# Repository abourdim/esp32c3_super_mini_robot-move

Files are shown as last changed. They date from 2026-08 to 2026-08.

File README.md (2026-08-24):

# 🤖 esp32c3_super_mini_robot-move — b3 on the `30_esp32_c3_move` board

A port of [`esp32c3_super_mini_robot-bit-rxy`](https://github.com/abourdim/esp32c3_super_mini_robot-bit-rxy)
("b3") onto the **`30_esp32_c3_move`** carrier board, plus a panning sonar head
the original does not have. Driven over Bluetooth Low Energy from the
[rxy web app](https://github.com/abourdim/rxy_web) — no install, no account, no
WiFi.

**The robot owns the layout.** The app is a generic renderer: it connects, asks
the robot for its panel, and draws whatever comes back. There is no per-robot
build of the app.

## Faithful to b3

Every module b3 has is still in the tree — buzzer, NeoPixels, battery sense,
board LEDs, OLED, both NeoPixel demos, all eight panels. Nothing was deleted.
What changed is the pin map, because the two carrier boards share an MCU and
nothing else.

What is **not fitted** on this build is switched off at a single `#define`
each, so it compiles out rather than failing at runtime:

| feature | b3 | here | state |
|---|---|---|---|
| left / right drive servo | GPIO 6 / 3 | **5 / 10** — J5 / J12, level-shifted | ✅ |
| HC-SR04 | 21 / 20 | **6 / 7** — J10, level-shifted | ✅ |
| head servo | *(none)* | **1** — J6 | ✅ |
| button / OTA | 0 (module BOOT) | **3** — SW1 | ✅ |
| green / red LED | 1 / 10 | **0 / 21** — J7 / J8 | ✅ |
| NeoPixel strip | 5 (or 10) | 20 — J9 | `CONFIG_NEOPIXELS_ENABLED 0` |
| buzzer | 4 | 4 — SW2 pads | `CONFIG_BUZZER_ENABLED 0` |
| battery sense | 4 | 4 — SW2 pads, **no divider on the board** | reads meaningless |
| OLED | I²C 8 / 9 | 8 / 9 — module pads, **not wired** | `CONFIG_OLED_ENABLED 0` |

Turning the strip off is worth more than it looks: its default French-flag
effect calls `delay(1000/60)` on **every** `loop()` iteration, so an absent
strip still paced the whole robot at 60 Hz to animate nothing.

The OLED keeps its runtime presence-probe for the day the wires go on, but with
the feature off nothing touches the I²C bus at all — not even the five-second
re-probe, which would otherwise poke a dead bus forever. Set
`CONFIG_OLED_ENABLED 1` once SDA/SCL/3V3/GND are on the module's pads; nothing
else needs changing. Wiring and the strapping-pin reasoning:
[`02_hardware/README.md`](02_hardware/README.md#attaching-the-oled).

Board source and the full netlist-derived pin map: [`02_hardware/`](02_hardware/).

## Three servos need four PWM timers

b3 allocates **one** LEDC timer and attaches two servos, which exactly fits.
The head makes three, and ESP32Servo does not warn when it runs short — it
prints `All PWM timers allocated! Can't accomodate 50.000 Hz` and **halts
inside `attach()`**, so `setup()` never returns.

That failure is invisible from outside. NimBLE has already started on its own
task by then, so the robot still advertises and the app still connects; it just
never answers anything, because `remotexy_handler()` lives in `loop()` and
`loop()` has never run. It presents as a protocol bug and is not one.

`setup()` now allocates all four.

## The 3-pin headers double as FET gates

J6, J7, J8 and J9 carry the same nets as Q1–Q4's gates, which drive the J1–J4
screw terminals and their yellow indicator LEDs. Anything plugged into a 3-pin
header switches its paired screw terminal in sympathy, so **leave J1–J4
unpopulated**. The upside is free activity indicators: D6–D9 light along with
whatever is on the header, so the link LEDs are visible even with nothing
plugged in.

## Why the button moved off GPIO 0

b3 uses the SuperMini's own BOOT button for the three-second OTA hold, and that
button exists here too. But on this board GPIO 0 is Q2's gate, so the gesture
would switch the J2 output on for the length of the hold — and GPIO 0 is more
useful as the green LED. SW1 is a real button with its own pull-up that drives
nothing else.

## Drive direction

`CONFIG_SERVO_INVERT_DRIVE` flips both channels. Both wheels ran backwards on
this chassis — that is motor polarity, not a left/right mix-up, and swapping
the two pins would have given a robot that spins instead. The flip is applied
to the command before the mix becomes pulses, so trim and the speed cap stay in
the frame they were written for, and it corrects the steering with it: with the
polarity wrong, a spin-left command was coming out as spin-right.

## The head, the radar, and sweep

The head servo is the one thing here that b3 does not have. It gives the app's
**radar** widget a bearing to plot against — the radar carries no value of its
own, it reads the distance gauge and the head slider by id.

**Sweep** is a toggle in the DISTANCE group. The head steps one notch per
telemetry pass rather than on a timer of its own, and the step happens *after*
the pass has sent this cycle's distance and angle. That ordering is the point:
the radar plots (angle, distance) pairs, and stepping independently would paint
readings at bearings the sensor was not pointing at when they were taken. Each
step then gets a full 500 ms to settle before the next measurement. 15° steps
across 10–170° is about 5.5 s per sweep.

Reversal happens **at** each limit, not past it. `moveHead()` clamps anyway,
but bouncing off the clamp parks the head on its end stop for an extra pass
every sweep — a stutter on the scope, and a stalled servo while it lasts.

Dragging the slider takes the head off sweep, otherwise the servo fights you
and the slider snaps back on the next pass. Leaving sweep re-centres.

The bearing is published every telemetry pass. Without that the radar plots at
whatever `head` last reported, which was its default — the head would sweep and
the scope would show a beam frozen at 90°.

**Head trim** (`head_off`, plus H−1 / H+1 buttons) is mechanical centring: a
pan mount is glued or screwed on by hand, so commanding 90° almost never points
dead ahead. The offset is applied where the servo is *written*, not to the
bearing that gets reported — the radar has to plot where the sensor is really
aimed, which is the corrected direction. Like the wheel trims it lives in NVS,
because it describes how the robot was assembled rather than how it is being
driven; and like them it rides the save-settle, so dragging the slider across
its range costs one flash write rather than sixty.

`CONFIG_SERVO_HEAD_MIN` / `_MAX` are the **mechanical** limits of your pan
mount, not 0–180. Narrow them to what the mount clears — a servo told to go
past its stop sits there stalled, drawing full stall current off the same rail
as the C3.

## Panels

b3's eight, plus a ninth — **Radar** — switched with the **Level** selector;
the choice is kept in NVS. The Radar panel is one subsystem on its own: the
scope, the head slider, Sweep, the head trim, and the distance readout the
radar is plotting, so the panel explains itself — you can see the number each
blip came from.

The new level is appended to the enum rather than inserted, because the level
index lives in NVS: renumbering the existing entries would silently move an
upgraded robot to a different panel. And since every layout carries its own
copy of the selector's options, all nine blobs were rewritten — otherwise the
new level would be unreachable from wherever you happened to be.

Expert has been cut down to what this board actually has:

- **removed** — the DISPLAY group (no OLED) and the SOUND group (no buzzer)
- **removed** — the six strip widgets from LIGHTS; the two board LEDs stay,
  they are real, and their J7/J8 headers light the onboard yellows too
- **moved** — TRIM is no longer its own group; all eight widgets sit inside
  DRIVE, which is where you use them, tuning while driving and watching the pull
- **added** — the head slider, the sweep toggle, and the radar, in DISTANCE

> ⚠️ **`gen_test_layouts.py` writes `test_decls.h`, which nothing includes.**
> The live blobs are hardcoded in `03_bit-rxy.cpp`, so running the generator
> changes nothing that reaches the board. It needs a splice step — S2's
> `gen_layouts.py` has the logic to copy — or it should be deleted. Until then,
> layout edits go into the blobs directly.

## Build and flash

```bash
cd 01_software/01_app && pio run -e esp32-c3-devkitm-1 -t upload
```

After the first USB flash, hold **SW1 for 3 seconds** to enter WiFi OTA mode.
Hold to 8 seconds to forget the saved network. The device is reachable as
`wdiy-move`, and the setup AP is `WDIY-Robot-Setup`.

BLE device name is `diy_app_mv`, distinct from b3's `diy_app_b3` so the two are
told apart in the scanner when both are powered on in the same room.

**The image is at 91.5% of flash** — roughly 110 KB spare on the default
partition table. Enough for tuning, not for another subsystem.

Note that with native USB-CDC the serial monitor attaches *after* boot, so you
will usually see nothing at startup. That is normal, not a fault.

## Before you build one

Three board facts firmware cannot paper over — the long form is in
[`02_hardware/README.md`](02_hardware/README.md):

- **J1–J4 must stay unpopulated** while anything is on J6–J9. Same nets.
- **J6 has no level shifter.** J5, J12 and J10 run through the TXB0104 and get
  clean 5 V logic; J6 carries the raw 3.3 V pin. Most hobby servos accept that.
- **The servo rail needs 470–1000 µF** at the connectors, fed from the input
  terminal rather than through the SuperMini's 5 V pin. Three drive servos on a
  rail with 100 nF browns the C3 out mid-drive, which reads as a random reboot.

## Known issues

- **Trim is applied with the wrong sign**, inherited from b3. It is added to
  both wheels, but the right channel's pulse range is inverted, so a positive
  trim pushes the two wheels in *opposite* physical directions. With b3's
  defaults of `5`/`5` an idle robot slowly rotates on the spot. Either zero the
  two `CONFIG_SERVO_SPEED_STOP_*_OFFSET` values or port S2's fix (`10c1468`),
  which subtracts on the inverted side.
- **`01_software/01_app/02_web/`** is b3's site and still describes b3's pin
  map. Its Pages workflow is set to manual trigger only, so a push cannot
  publish a site that is wrong about this robot. Rewrite it before re-enabling.

## Wiki

A full illustrated walkthrough — clone, build, flash, verify, plus the board's
pin map and how the sweep is paced — is on the wiki in three languages:

- [Robot MV (English)](https://abourdim.github.io/wiki/robot-mv-en.html)
- [Robot MV (Français)](https://abourdim.github.io/wiki/robot-mv.html)
- [Robot MV (العربية)](https://abourdim.github.io/wiki/robot-mv-ar.html)

Powered by [Workshop-DIY.org](https://workshop-diy.org)

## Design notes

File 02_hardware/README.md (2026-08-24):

# 🔌 Hardware

KiCad source, PCB renders and fab output for **`30_esp32_c3_move`**, the board
this firmware targets. Upstream lives at `01_kicad/30_esp32_c3_move/`.

## Versions

| Version | Status | Folder |
|---|---|---|
| **v1** | ✅ **Current — fabricated, and what the firmware is written against** | [`v1/`](v1/) |
| v2 | 📝 Planning stub, not a revision | [`v2/`](v2/) |

**v2 is not a new board.** Its PCB is byte-identical to v1 and it carries the
same 98 components; the only differences are one schematic block nudged 14 mm,
a project rename, and a to-do note dated 02/06/2025:

> add 2 neo pixel · oled connector · buzzer · battery level · large soldering
> footprint for the transistor

None of those are implemented. It is kept here because it is where that plan is
written down, not because it builds anything different.

## The pin map, and where it came from

Read out of `v1/30_esp32_c3_move.kicad_pcb` by walking footprint pads to nets —
**not** from the schematic, which labels every net `gpio_NN` and records nothing
about what it drives. `00_config.h` is the firmware-side copy of this table.

| GPIO | Connector | Used for |
|---|---|---|
| 5 | J5, 3-pin, via TXB0104 | left drive servo |
| 10 | J12, 3-pin, via TXB0104 | right drive servo |
| 6 / 7 | J10, 4-pin, via TXB0104 | HC-SR04 trig / echo |
| 1 | J6, 3-pin, **raw 3.3 V** · also Q1 gate → J1 | head servo |
| 0 | J7, 3-pin · also Q2 gate → J2 | green LED |
| 21 | J8, 3-pin · also Q3 gate → J3 | red LED |
| 20 | J9, 3-pin · also Q4 gate → J4 | NeoPixel strip |
| 3 | SW1, 10k pull-up R10 | button, OTA hold |
| 4 | SW2, 10k pull-up R11 | 🔧 buzzer + battery sense, bodged to the pads |
| **2, 8, 9** | **nowhere — module pads only** | 🔧 OLED on 8/9, four wires |

The four 3-pin headers are the same nets as the FET gates, so anything on
J6–J9 switches its paired screw terminal too. **Leave J1–J4 unpopulated.** The
compensation is that D6–D9 become free activity indicators for whatever is on
the header.

Each switched output has a 1N4007 flyback (D1–D4), a 10k gate pull-down
(R6–R9) and a yellow state LED (D6–D9 + R1–R4). The SK12D07VG4 slide switch
gates the input rail; J11 (screw) and J13 (JST-PH) both feed it.

## Three things to know before building one

**The 3-pin headers share nets with the screw terminals.** GPIO 1 is Q1's gate
*and* J6's signal pin; the same pairing holds for J7/J2, J8/J3 and J9/J4. A
servo on J6 pulses the J1 output at 50 Hz and flickers D6 continuously; a load
on J1 makes the head twitch. Populate the header or the terminal, never both.
Firmware cannot arbitrate this — it is a copper fact.

**J6 has no level shifter.** J5, J12 and J10 all run through the TXB0104 and
get clean 5 V logic. J6 carries the raw 3.3 V pin. Most hobby servos accept
that; a fussy one is the case where this board bites.

**The servo rail needs bulk capacitance.** Three servos share `VCC` with the
ESP32 and v1 has only 100 nF on that rail. An SG90 pulls ~700 mA stalled with
a larger startup surge, and these are drive servos — they run constantly. Add
**470–1000 µF at the servo connectors**, and feed servo power straight from the
input terminal rather than through the SuperMini's 5 V pin, so servo current
does not run through the module. Without this the rail dips and the C3 browns
out mid-drive, which reads as a random reboot.

## Attaching the OLED

GPIO 2, 8 and 9 reach the SuperMini's pads and no connector, so the SSD1306 is
four wires soldered to the module itself. This is what v2's "oled connector"
note is meant to fix.

| OLED pin | goes to |
|---|---|
| SDA | module **GPIO 8** |
| SCL | module **GPIO 9** |
| VCC | module **3V3** — *not* 5V, see below |
| GND | any GND |

**Take VCC from 3V3, not 5V.** Most SSD1306 modules accept either, but the
module's own I2C pull-up resistors go to whatever you feed it. On 5V those
pull-ups would hold SDA and SCL at 5V, and the C3's GPIOs are not 5V tolerant.

**The pull-ups are also what make the board boot.** GPIO 8 and 9 are both
strapping pins on the ESP32-C3, and both need to be high at reset — GPIO 9 low
at reset is what selects download mode. The module's pull-ups hold them there,
which is exactly why this pin pair works on b3 too. Flashing still works
normally: the module's BOOT button pulls GPIO 9 low against the pull-up.

The firmware probes `0x3C` at boot and re-probes every five seconds while no
screen is answering, so a wire that makes contact late or works loose recovers
without a power cycle. Watch serial for `[OLED] found` or `[OLED] appeared on
the bus`. If you get neither, the usual cause is a module strapped to **0x3D**
instead of 0x3C — some boards have a solder jumper for it.

Powered by [Workshop-DIY.org](https://workshop-diy.org)

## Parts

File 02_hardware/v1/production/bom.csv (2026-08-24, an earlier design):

Designator | Footprint | Quantity | Value | LCSC Part #
C1, C2 | 0805 | 2 | 100nF
D1, D2, D3, D4 | D_SOD-123F | 4 | 1N4007
D6, D7, D8, D9 | 0805 | 4 | yellow
J1, J11, J2, J3, J4 | TerminalBlock_Phoenix_MPT-0,5-2-2.54_1x02_P2.54mm_Horizontal | 5 | Screw_Terminal_01x02
J10 | PinHeader_1x04_P2.54mm_Vertical | 1 | Conn_01x04_Pin
J12, J5, J6, J7, J8, J9 | PinHeader_1x03_P2.54mm_Vertical | 6 | Conn_01x03_Pin
J13 | JST_PH_S2B-PH-K_1x02_P2.00mm_Horizontal | 1 | Conn_01x02_Pin
Q1, Q2, Q3, Q4 | SOT-23_Handsoldering | 4 | 2N7002
R1, R2, R3, R4 | 0805 | 4 | 1k
R10, R11, R5, R6, R7, R8, R9 | 0805 | 7 | 10k
SW1, SW2 | SW_Push_1P1T_NO_6x6mm_H9.5mm | 2 | SW_Omron_B3FS
U1 | MODULE_ESP32-C3_SUPERMINI | 1 | ESP32-C3_SUPERMINI
U2 | SK12D07VG4 | 1 | SK12D07VG4
U3 | TSSOP-14_4.4x5mm_P0.65mm | 1 | TXB0104PW

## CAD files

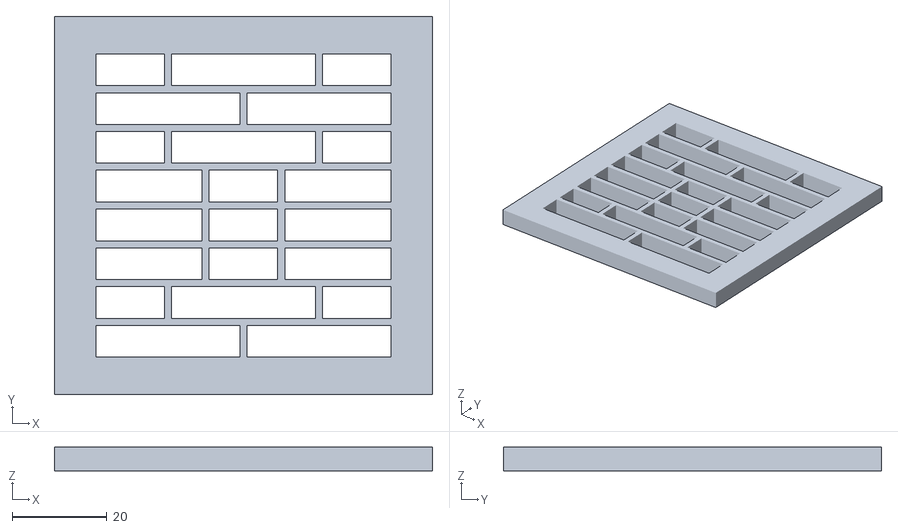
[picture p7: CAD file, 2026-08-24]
01_software/4_wled/WLED/usermods/word-clock-matrix/Word Clock Baffle.stl
80.0 x 80.0 x 5.00

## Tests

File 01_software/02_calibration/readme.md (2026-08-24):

# Wheel calibration sketch

Finds each wheel's true stop point on continuous-rotation servos. Same BLE/OLED/OTA plumbing as `01_app`, but the widgets drive raw servo pulses directly (0-180) instead of the arcade-mixed joystick/D-Pad — no guessing which combined stick position corresponds to a given pulse.

## Flash it

```bash
cd 01_software/02_calibration
./launch.sh flash
```

## Use it

Open [bit-rxy](https://abourdim.github.io/bit-rxy/), connect to `diy_calib_b3`. Layout:

- **Left / Right sliders** — drag for coarse adjustment (0-180).
- **Left # / Right # edit fields** — type an exact number for fine adjustment; slider and edit field for the same wheel share state, whichever you touched last wins.
- **Center button** — resets both wheels to 90 (stop).

The OLED shows the live pulse value for each wheel as you adjust. Watch the actual wheel: find the pulse value where it visibly stops turning, note it down, and put it in `01_app/01_src/00_config.h` as `CONFIG_SERVO_SPEED_STOP_LEFT`/`_RIGHT` (plus whatever small `_OFFSET` correction gets it dead-centered).

## OTA

Same as `01_app` — hold the debug button ~3s to reconnect to the last WiFi network, ~8s to forget it and open the `WDIY-Calib-Setup` portal. See the [wiki article's OTA section](https://abourdim.github.io/wiki/wdiy-robot-en.html#ota) for the full walkthrough (applies identically here, just a different AP/hostname).

```bash
./ota_flash.sh <robot-ip>
```

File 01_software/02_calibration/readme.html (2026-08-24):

# 🔧 Wheel Calibration

Finds each wheel's true stop point on continuous-rotation servos — same BLE/OLED/OTA plumbing as the main app, but widgets drive raw servo pulses (0–180) directly.

## 🚀 Flash it

cd 01_software/02_calibration
./launch.sh flash

## 🎛️ Use it

Open bit-rxy (https://abourdim.github.io/bit-rxy/), connect to diy_calib_b3. Layout:

- Left / Right sliders — drag for coarse adjustment (0–180)
- Left # / Right # edit fields — type an exact number for fine adjustment; slider and edit field for the same wheel share state, whichever you touched last wins
- Center button — resets both wheels to 90 (stop)

The OLED shows the live pulse value for each wheel as you adjust. Watch the actual wheel: find the pulse value where it visibly stops turning, note it down, and put it in 01_app/01_src/00_config.h as CONFIG_SERVO_SPEED_STOP_LEFT/_RIGHT (plus whatever small _OFFSET correction gets it dead-centered).

## 📡 OTA

Same as the main app — hold the debug button ~3s to reconnect to the last WiFi network, ~8s to forget it and open the WDIY-Calib-Setup portal. See the wiki article's OTA section (https://abourdim.github.io/wiki/wdiy-robot-en.html#ota) for the full walkthrough (applies identically here, just a different AP/hostname).

./ota_flash.sh <robot-ip>

Workshop-DIY — part of the esp32c3_super_mini_robot-bit-rxy (https://github.com/abourdim/esp32c3_super_mini_robot-bit-rxy) project.

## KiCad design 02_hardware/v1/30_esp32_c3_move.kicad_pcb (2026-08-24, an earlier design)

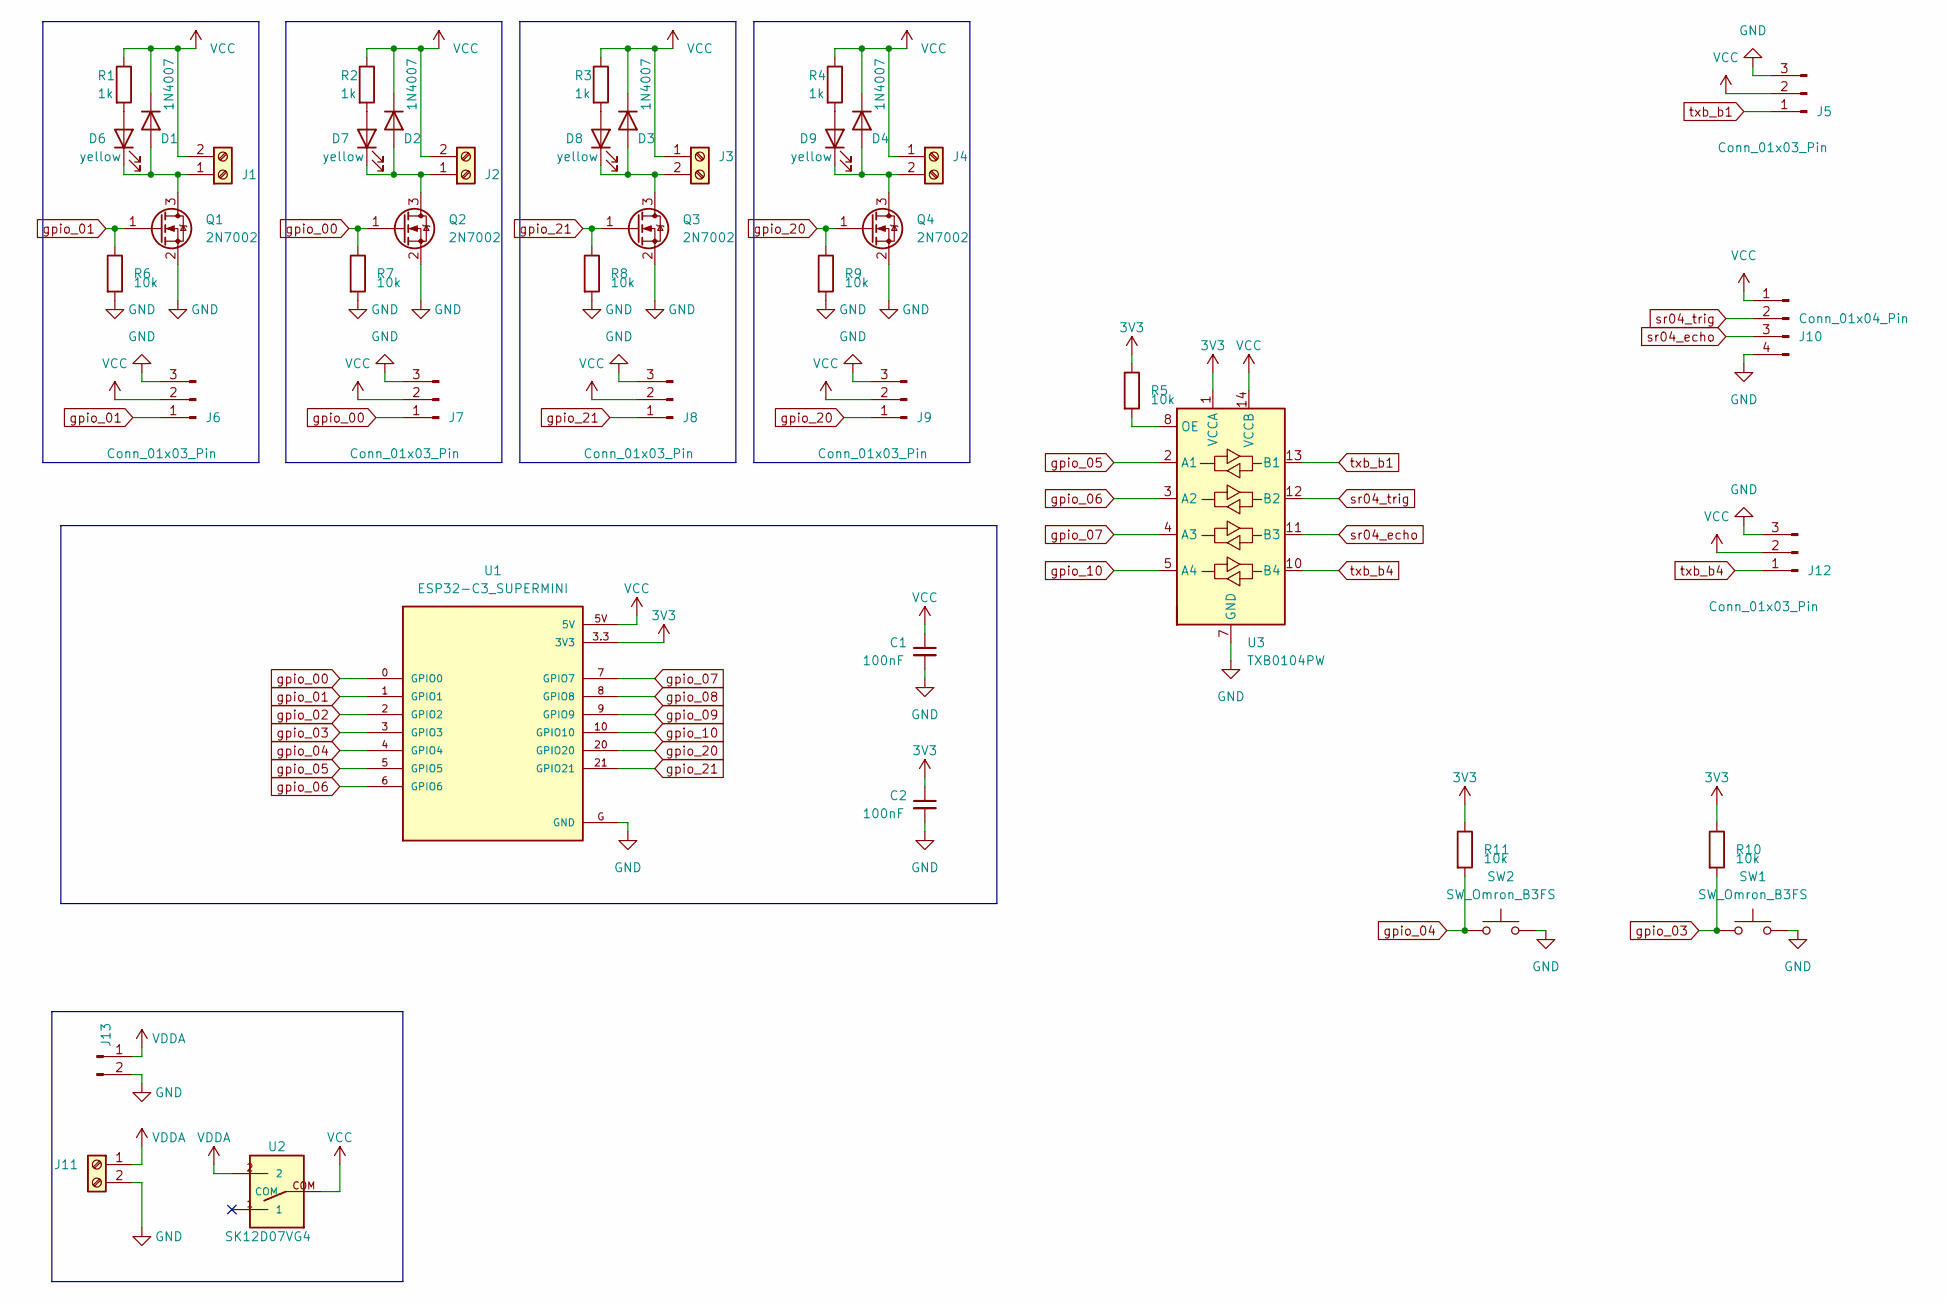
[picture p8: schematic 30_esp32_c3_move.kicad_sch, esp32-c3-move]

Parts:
C1, C2: 100nF; C_0805_2012Metric
D1, D2, D3, D4: 1N4007; D_SOD-123F
D6, D7, D8, D9: yellow; LED_0805_2012Metric_Pad1.15x1.40mm_HandSolder
J1, J2, J3, J4, J11: Screw_Terminal_01x02; TerminalBlock_Phoenix_MPT-0,5-2-2.54_1x02_P2.54mm_Horizontal
J5, J6, J7, J8, J9, J12: Conn_01x03_Pin; PinHeader_1x03_P2.54mm_Vertical
J10: Conn_01x04_Pin; PinHeader_1x04_P2.54mm_Vertical
J13: Conn_01x02_Pin; JST_PH_S2B-PH-K_1x02_P2.00mm_Horizontal
Q1, Q2, Q3, Q4: 2N7002; SOT-23_Handsoldering
R1, R2, R3, R4: 1k; R_0805_2012Metric
R5, R6, R7, R8, R9, R10, R11: 10k; R_0805_2012Metric
SW1, SW2: SW_Omron_B3FS; SW_Push_1P1T_NO_6x6mm_H9.5mm; lcsc C2837532
U1: ESP32-C3_SUPERMINI; MODULE_ESP32-C3_SUPERMINI
U2: SK12D07VG4
U3: TXB0104PW; TSSOP-14_4.4x5mm_P0.65mm

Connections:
3V3: C2.1, R5.1, R10.1, R11.1, U1.3.3 (3V3), U3.1 (VCCA)
GND: C1.2, C2.2, J5.3, J6.3, J7.3, J8.3, J9.3, J10.4, J11.2, J12.3, J13.2, Q1.2 (S), Q2.2 (S), Q3.2 (S), Q4.2 (S), R6.2, R7.2, R8.2, R9.2, SW1.2, SW2.2, U1.G (GND), U3.7 (GND)
unnamed: D1.2 (A), D6.1 (K), J1.1, Q1.3 (D)
unnamed: D2.2 (A), D7.1 (K), J2.1, Q2.3 (D)
unnamed: D3.2 (A), D8.1 (K), J3.2, Q3.3 (D)
unnamed: D4.2 (A), D9.1 (K), J4.2, Q4.3 (D)
unnamed: D6.2 (A), R1.2
unnamed: D7.2 (A), R2.2
unnamed: D8.2 (A), R3.2
unnamed: D9.2 (A), R4.2
unnamed: R5.2, U3.8 (OE)
VCC: C1.1, D1.1 (K), D2.1 (K), D3.1 (K), D4.1 (K), J1.2, J2.2, J3.1, J4.1, J5.2, J6.2, J7.2, J8.2, J9.2, J10.1, J12.2, R1.1, R2.1, R3.1, R4.1, U1.5V, U2.COM, U3.14 (VCCB)
VDDA: J11.1, J13.1, U2.2
gpio_00: J7.1, Q2.1 (G), R7.1, U1.0 (GPIO0)
gpio_01: J6.1, Q1.1 (G), R6.1, U1.1 (GPIO1)
gpio_02: U1.2 (GPIO2)
gpio_03: R10.2, SW1.1, U1.3 (GPIO3)
gpio_04: R11.2, SW2.1, U1.4 (GPIO4)
gpio_05: U1.5 (GPIO5), U3.2 (A1)
gpio_06: U1.6 (GPIO6), U3.3 (A2)
gpio_07: U1.7 (GPIO7), U3.4 (A3)
gpio_08: U1.8 (GPIO8)
gpio_09: U1.9 (GPIO9)
gpio_10: U1.10 (GPIO10), U3.5 (A4)
gpio_20: J9.1, Q4.1 (G), R9.1, U1.20 (GPIO20)
gpio_21: J8.1, Q3.1 (G), R8.1, U1.21 (GPIO21)
sr04_echo: J10.3, U3.11 (B3)
sr04_trig: J10.2, U3.12 (B2)
txb_b1: J5.1, U3.13 (B1)
txb_b4: J12.1, U3.10 (B4)

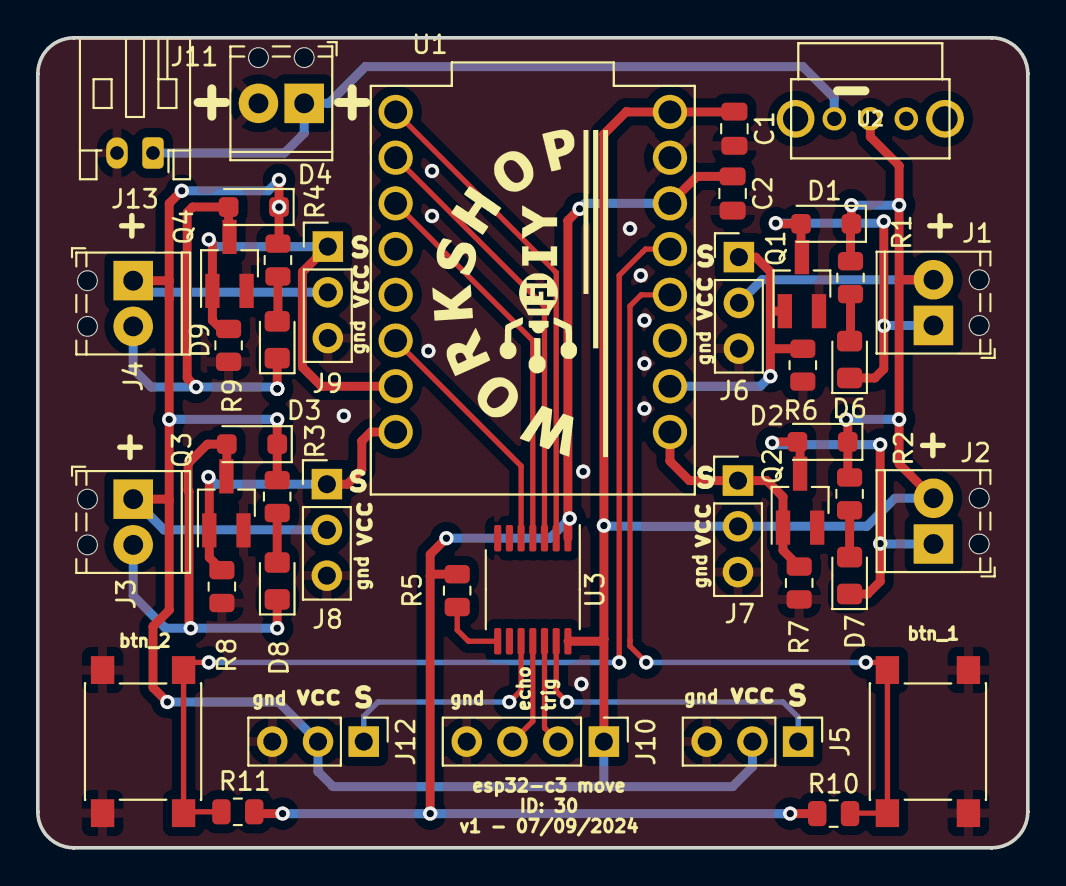
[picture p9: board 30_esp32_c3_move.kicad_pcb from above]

Board: 2 copper layers, 55.0 x 45.0 mm, 43 parts (0 on the bottom side), 27 nets.

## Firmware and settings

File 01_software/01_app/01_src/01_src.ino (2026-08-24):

///////////////////////////////////////////////
//        RemoteXY include library          //
//////////////////////////////////////////////

#include "01_includes.h"

Adafruit_SSD1306 display(SCREEN_WIDTH, SCREEN_HEIGHT, &Wire, OLED_RESET);

// ===========================================================================
void setup() {
// ===========================================================================

  // Serial for debugging
  #ifdef DEF_DERIAL_DEBUG
  Serial.begin(115200);
  #endif

  // Initialize RemoteXY
  //RemoteXY_Init();

  remotexy_init();
  
  // Allocate timers for ESP32 PWM. b3 allocates ONE and attaches two servos,
  // which exactly fits. This board has a third (the head on J6), and one more
  // servo than timers is not a warning -- ESP32Servo prints "All PWM timers
  // allocated! Can't accomodate 50.000 Hz" and then HALTS inside attach(), so
  // setup() never returns and loop() never runs.
  //
  // That failure is deceptively quiet from the outside: NimBLE has already
  // started on its own task by this point, so the robot still advertises and
  // the app still connects -- it just never gets an answer to anything,
  // because remotexy_handler() lives in loop(). It looks like a protocol bug
  // and is not one.
  ESP32PWM::allocateTimer(0);
  ESP32PWM::allocateTimer(1);
  ESP32PWM::allocateTimer(2);
  ESP32PWM::allocateTimer(3);

  // Attach servos to their pins. All three run at 50Hz, so they share the one
  // LEDC timer allocated above -- the C3 has six channels and four timers, and
  // three servos on one timer is well inside that.
  servoLeft.attach(CONFIG_PIN_SERVO_LEFT);
  servoRight.attach(CONFIG_PIN_SERVO_RIGHT);
  servoHead.attach(CONFIG_PIN_SERVO_HEAD);

  // Stop both servos initially
  stopServos();

  // Point the head straight ahead before anything else moves. ESP32Servo parks
  // a freshly attached channel wherever it happened to sit; centring makes the
  // first radar sweep start from a known bearing.
  centerHead();

  #if CONFIG_OLED_ENABLED
  // Set custom I2C pins
  Wire.begin(CONFIG_PIN_OLED_SDA, CONFIG_PIN_OLED_SCL);

  // Probe before initialising, so an absent screen is detected rather than
  // written to. Writing a frame to a bus with no device is ~1KB of
  // transactions that each have to time out, and oled_update() runs every
  // 100ms -- enough to starve loop() and stop the robot answering the app.
  Wire.beginTransmission(0x3C);
  const bool oledFound = (Wire.endTransmission() == 0);
  oled_set_present(oledFound);

  #ifdef DEF_DERIAL_DEBUG
  Serial.printf("[OLED] %s on I2C %d/%d
",
                oledFound ? "found" : "absent - screen disabled",
                CONFIG_PIN_OLED_SDA, CONFIG_PIN_OLED_SCL);
  #endif

  if (oledFound) {
    if (!display.begin(SSD1306_SWITCHCAPVCC, 0x3C)) {
      #ifdef DEF_DERIAL_DEBUG
      Serial.println(F("SSD1306 allocation failed"));
      #endif
      oled_set_present(false);
    } else {
      display.clearDisplay();
      display.setTextColor(SSD1306_WHITE);
    }
  }
  #else
  // No screen on this board. Latched false so every draw site short-circuits
  // and nothing ever touches the I2C bus -- not even the periodic re-probe.
  oled_set_present(false);
  #endif

  leds_init();
  #if CONFIG_OLED_ENABLED
  oled_init();
  #endif

  ultrasonic_init();

  g_ultrasonic_distance_cm=0;
  g_elapsed_time_startup_millis = millis();  // Record start time

  #if CONFIG_NEOPIXELS_ENABLED
  neopixels_init();
  #endif

  #if CONFIG_BUZZER_ENABLED
  buzzer_init();
  buzzer_beep();
  #endif

  #if CONFIG_NEOPIXELS_ENABLED
  neopixels_all_blink(CRGB::Green, 3, 20);
  #endif

  remotexy_set_sound_01(REMOTEXY_SOUND_POWER_ON);  
  
  button_init();

    // Add battery pin setup
  pinMode(CONFIG_PIN_BATTERY_LEVEL, INPUT);  
   
  event_connection_state_flag_bo = remotexy_get_connect_flag();  // Set initial state

  g_battery_raw_adc = 0;
  g_battery_voltage = 0;
  g_battery_percentage = 0;

  g_previous_millis_u32 = 0;

}

// ===========================================================================
void loop() {
// ===========================================================================

  remotexy_handler();

  // Hold the debug button for CONFIG_OTA_HOLD_MS at any point during normal
  // operation to enter WiFi OTA mode instead of driving. Blocks forever if
  // triggered; only returns if the hold threshold hasn't been reached.
  ota_check_long_press();

  tasks_connect();
  tasks_buttons();
  tasks_joysticks();
  tasks_elapsed_time();
  tasks_rmotexy_sound();

  // The screen gets its own cadence rather than riding the 500ms telemetry
  // tick. Two reasons, and the first is why the eyes looked like they were not
  // following the driving at all: at 2Hz a D-pad press can start and finish
  // between two frames, so the pupils moved late or never. The second is that
  // this board can afford it -- the OLED has the I2C bus entirely to itself
  // here, because the servos are GPIO PWM. The micro:bit robots ration their
  // screen hard, but only because their motor driver shares the wire; copying
  // that caution here would pay a cost this board does not have.
  #if CONFIG_OLED_ENABLED
  {
    static uint32_t s_oled_at = 0;
    const uint32_t now_ms = millis();
    if (now_ms - s_oled_at >= 100) { s_oled_at = now_ms; oled_update(); }
  }
  #endif

  if (events_get_timeout_flag() == EVENTS_TIMEOUT_OCCURED) {

    ultrasonic_get_distance();
    tasks_battery();

    tasks_remotexy();
    leds_update();

  }

  events_reset_connect_flag();

  if (events_get_timeout_flag() == EVENTS_TIMEOUT_OCCURED) {
    events_reset_timeout_flag();
  }

  // NeoPixel strip — on/off, effect, colour and brightness all come from the
  // LIGHTS zone of the layout. This replaced an unconditional call to
  // neopixels_waving_french_flag(), which is still the default effect so the
  // out-of-the-box behaviour is unchanged until the user picks another.
  #if CONFIG_NEOPIXELS_ENABLED
  FastLED.setBrightness(remotexy_get_np_brightness());
  if (!remotexy_get_np_on()) {
    neopixels_all_clear(CRGB::Black);
  } else {
    switch (remotexy_get_np_effect()) {
      case NP_EFFECT_SOLID:
        neopixels_all_clear(CRGB(remotexy_get_np_color()));
        break;
      case NP_EFFECT_RAINBOW:
        // neopixels_rainbow() advances a shared static hue and writes one
        // pixel, so walking the strip paints a gradient rather than a
        // single colour. It does not show() itself.
        for (uint8_t i = 0; i < CONFIG_NEOPIXELS_NB_LEDS; ++i) neopixels_rainbow(i);
        FastLED.show();
        break;
      case NP_EFFECT_KNIGHT:
        neopixels_KnightRiderRedEyewithTail();
        break;
      case NP_EFFECT_DUEL:
        neopixels_duel_eye();
        break;
      default:
        neopixels_waving_french_flag();
        break;
    }
  }
  #endif
}

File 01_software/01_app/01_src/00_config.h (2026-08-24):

#ifndef __DEF_INCLUDE_CONFIG_H__
#define __DEF_INCLUDE_CONFIG_H__


// Distinct from b3 ("diy_app_b3") so the two are told apart in the app's
// scanner when both are powered on in the same room.
#define CONFIG_BLE_DEVICE_NAME "diy_app_mv"

#define DEF_DERIAL_DEBUG


// ===========================================================================
// Board: 30_esp32_c3_move rev v1  (02_hardware/v1)
// ===========================================================================
// This is a port of b3, kept faithful to it: every module b3 has is still
// here. What changed is the pin map, because the two carrier boards share an
// MCU and nothing else. The map below was read out of the PCB netlist, not the
// schematic -- the schematic names every net `gpio_NN` and records nothing
// about what it drives.
//
// The board's connectors:
//
//   J5  -- 3-pin, GPIO 5,  via TXB0104 level shifter   -> LEFT drive servo
//   J12 -- 3-pin, GPIO 10, via TXB0104 level shifter   -> RIGHT drive servo
//   J10 -- 4-pin, GPIO 6/7, via TXB0104                -> HC-SR04
//   J6  -- 3-pin, GPIO 1,  raw 3.3V                    -> HEAD servo
//   J7  -- 3-pin, GPIO 0   (also Q2 gate -> J2)        -> GREEN led
//   J8  -- 3-pin, GPIO 21  (also Q3 gate -> J3)        -> RED led
//   J9  -- 3-pin, GPIO 20  (also Q4 gate -> J4)        -> NeoPixel strip
//   SW1 -- GPIO 3, 10k pull-up R10                     -> button / OTA
//   SW2 -- GPIO 4, 10k pull-up R11                     -> buzzer + battery
//
// THE 3-PIN HEADERS DOUBLE AS FET GATES. J6/J7/J8/J9 carry the same net as
// Q1/Q2/Q3/Q4's gates, which drive the J1/J2/J3/J4 screw terminals and their
// yellow indicator LEDs. Anything plugged into a 3-pin header switches its
// paired screw terminal in sympathy. Leave J1-J4 UNPOPULATED. The upside: the
// onboard yellow LEDs (D6-D9) become free activity indicators for whatever is
// on the header.
//
// THREE FEATURES NEED WIRES. GPIO 2, 8 and 9 reach the SuperMini's pads and no
// connector at all, and the board has no buzzer and no battery divider. The
// OLED, buzzer and battery sense below are therefore bodge-only -- see the
// notes at each. Every other b3 feature lands on a real connector.
// ===========================================================================


// --------------------------------------
// button
//
// SW1 on the carrier board. b3 uses GPIO 0, the module's own BOOT button, and
// that button physically exists here too -- but on THIS board GPIO 0 is Q2's
// gate, so the three-second OTA hold would switch the J2 output on for the
// duration of the hold, and GPIO 0 is more useful as the green LED. SW1 is a
// real button with its own pull-up that drives nothing else.
#define CONFIG_PIN_BUTTON 3

// --------------------------------------
// WiFi OTA — off by default (no WiFi during normal BLE-driven play). Hold
// the debug button for CONFIG_OTA_HOLD_MS at any point during normal
// operation to enter OTA mode instead. No SSID/password hardcoded here:
// WiFiManager remembers the last network it joined (its own NVS storage),
// and opens a setup access point for you to enter new credentials from a
// phone whenever it can't reconnect — see 17_ota.cpp.
#define CONFIG_OTA_HOSTNAME          "wdiy-move"
#define CONFIG_OTA_HOLD_MS           3000
#define CONFIG_OTA_SETUP_AP_NAME     "WDIY-Robot-Setup"
#define CONFIG_OTA_PORTAL_TIMEOUT_S  180
// Keep holding past CONFIG_OTA_HOLD_MS, all the way to this total, to
// forget the saved WiFi network and force the setup portal open — the
// normal path just reconnects to whatever's already saved.
#define CONFIG_OTA_FORGET_HOLD_MS    8000

// --------------------------------------
// buzzer
//
// BODGE ONLY -- there is no buzzer footprint on this board. GPIO 4 is SW2's
// pin, so a passive buzzer solders to SW2's pads; SW2 then reads as pressed
// whenever the line is driven low, which nothing uses. Kept on GPIO 4 because
// that is b3's buzzer pin, so the module itself is unchanged.
// OFF: no buzzer fitted. playTone() busy-waits the full note with
// delayMicroseconds(), so leaving it enabled costs loop() time to make
// silence.
#define CONFIG_BUZZER_ENABLED 0

#define CONFIG_PIN_BUZZER 4
#define CONFIG_BUZZER_FREQ 4000

// battery level
//
// BODGE ONLY, and it shares GPIO 4 with the buzzer exactly as b3 does. b3's
// board has a divider feeding this pin; THIS board has none, so without one
// wired to SW2's pads the reading is meaningless rather than merely noisy.
// The Power test panel puts a Buzz button next to the live voltage for the
// same reason it does on b3: the interaction is visible, not hidden.
#define CONFIG_PIN_BATTERY_LEVEL 4

#define BATTERY_MIN_V 3.3  // Minimum battery voltage (adjust according to your battery)
//#define BATTERY_MAX_V 4.2  // Maximum battery voltage (adjust according to your battery)
#define BATTERY_MAX_V 4.5  // Maximum battery voltage (adjust according to your battery)

// --------------------------------------
// neopixel
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

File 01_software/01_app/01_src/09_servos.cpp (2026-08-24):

#include "01_includes.h"


// ===========================================================================
void moveServos(int32_t leftSpeed, int32_t rightSpeed) {
// ===========================================================================
  leftSpeed = constrain(leftSpeed, 0, 180);
  rightSpeed = constrain(rightSpeed, 0, 180);

  // moveServos() runs from tasks_joysticks() on every loop() iteration.
  // Skip redundant PWM writes when the value hasn't changed, and cap the
  // rate to ~50Hz otherwise — servos don't respond faster than that, and
  // the app itself already throttles incoming joystick messages to ~200ms.
  static uint32_t s_lastWriteMillis = 0;
  static bool     s_hasWritten = false;
  uint32_t now = millis();
  bool changed = (leftSpeed != (int32_t)g_speed_s1) || (rightSpeed != (int32_t)g_speed_s2);
  if (changed && (!s_hasWritten || (now - s_lastWriteMillis >= 20))) {
    servoLeft.write(leftSpeed);
    servoRight.write(rightSpeed);
    g_speed_s1 = leftSpeed;
    g_speed_s2 = rightSpeed;
    s_lastWriteMillis = now;
    s_hasWritten = true;
  }

  // For debugging
  #ifdef DEF_DERIAL_DEBUG
  // Serial.printf("Left: %d, Right: %d\n", leftSpeed, rightSpeed);
  #endif
}

// ===========================================================================
void stopServos() {
// ===========================================================================
  moveServos(CONFIG_SERVO_SPEED_STOP_LEFT, CONFIG_SERVO_SPEED_STOP_RIGHT);
}

// ===========================================================================
// Sonar head (J6)
// ===========================================================================
// Kept apart from moveServos() on purpose. Those two are continuous-rotation
// servos whose "angle" is really a speed, rewritten from the drive mix on every
// loop; this one is positional -- it moves when asked and then stays put.
// Sharing their rate limiter would make the head compete for the same 20ms
// budget as the drive channel for no reason.

static void headWrite(void);   // defined below moveHead()

static uint8_t s_head_angle  = CONFIG_SERVO_HEAD_CENTER;
static int8_t  s_head_offset = CONFIG_SERVO_HEAD_OFFSET;

// ===========================================================================
void moveHead(int32_t angle) {
// ===========================================================================
  // Clamped to what the mount clears, not to 0..180. A servo driven past its
  // mechanical stop sits there stalled, pulling full stall current off the same
  // rail as the C3 -- the brownout that reads as a random reboot mid-sweep.
  angle = constrain(angle, CONFIG_SERVO_HEAD_MIN, CONFIG_SERVO_HEAD_MAX);

  if ((uint8_t)angle == s_head_angle) return;   // no redundant PWM writes
  s_head_angle = (uint8_t)angle;
  headWrite();
}

// The bearing and the pulse are deliberately different numbers. s_head_angle is
// where the sensor is AIMED, which is what the radar plots and what the app
// echoes; the offset only exists between that and the pulse the servo gets.
// Clamped to 0..180 separately, because a legal bearing near a limit plus a
// large offset can still leave the servo's own range.
static void headWrite(void) {
  const int32_t pulse = constrain((int32_t)s_head_angle + s_head_offset, 0, 180);
  servoHead.write((int)pulse);
}

// ===========================================================================
void head_offset_set(int32_t deg) {
// ===========================================================================
  const int8_t v = (int8_t)constrain(deg, -CONFIG_SERVO_HEAD_OFFSET_LIMIT,
                                          CONFIG_SERVO_HEAD_OFFSET_LIMIT);
  if (v == s_head_offset) return;
  s_head_offset = v;
  // Rewritten immediately rather than waiting for the next moveHead(): the
  // whole point is watching the head swing while you drag the slider, and a
  // parked head would otherwise not move until something else commanded it.
  headWrite();
}

// ===========================================================================
int8_t head_offset_get(void) {
// ===========================================================================
  return s_head_offset;
}

// ===========================================================================
void centerHead() {
// ===========================================================================
  // NOT moveHead(): s_head_angle already starts at CONFIG_SERVO_HEAD_CENTER,
  // so moveHead()'s no-redundant-writes guard makes the boot call a no-op and
  // the head stays wherever it powered up. Centring has to be unconditional --
  // it is the one call whose whole job is to assert a position rather than
  // change one.
  s_head_angle = CONFIG_SERVO_HEAD_CENTER;
  headWrite();
}

// ===========================================================================
uint8_t headAngle() {
// ===========================================================================
  // The clamped value, deliberately. The radar plots blips at the bearing the
  // head really reached; echoing the unclamped request back would smear
  // detections across arc the sensor never pointed at.
  return s_head_angle;
}

// ===========================================================================
// Sweep mode
// ===========================================================================
// A distance sensor on a fixed head gives one number that changes for reasons
// you cannot see. Sweeping it turns the same sensor into a picture of the
// room, which is the whole reason the radar widget exists.
//
// Deliberately stepped by the caller rather than on its own timer -- see the
// call site in tasks_remotexy(). The radar plots (angle, distance) pairs, and
// those two have to have been true at the same moment: stepping independently
// would smear readings across bearings the sensor was not pointing at.

static bool   s_sweep_on  = false;
static int8_t s_sweep_dir = +1;

// ===========================================================================
void head_sweep_set(bool on) {
// ===========================================================================
  if (on == s_sweep_on) return;
  s_sweep_on = on;
  // Leaving sweep parks the head straight ahead rather than abandoning it at
  // whatever bearing the last step reached -- otherwise switching to manual
  // starts from a position the slider does not agree with.
  if (!on) centerHead();
}

// ===========================================================================
bool head_sweep_get(void) {
// ===========================================================================
  return s_sweep_on;
}
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

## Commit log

2026-08-19 chore: drop the placeholder readme
    It is empty, and its lowercase name collides with b3's README.md on a
    case-insensitive filesystem during the upcoming history merge.
2026-08-19 port: reduce b3 to the servo + sonar board (S2-v1)
    This board is b3 with the drive servos re-pinned and everything else gone:
    no buzzer, no battery sense, no NeoPixel strip, no board LEDs, no OLED.
    Pins. Servos move from GPIO 6/3 to 10/7, matching schematic
    34_richa_c3_servo_sonar rev v1 (J2 and J3). The SR04 is untouched on TRIG 21 /
    ECHO 20, so that path is already proven by b3. GPIO 10 is only free here
    because the LEDs and the external strip are gone -- on b3 it is
    CONFIG_PIN_LED_RED and the strip output.
    Kept, against the original plan: the BOOT button and WiFi OTA. GPIO0's button
    is on the SuperMini module itself, not the carrier board, so it is present even
    though this schematic rou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
    [01_bom_lcsc.xls, 1.stl, 37_rich_light_move_v1.kicad_pcb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]
2026-08-21 fix: the test-panel hint was clipped mid-sentence
    lbl_hint was 60px tall on both test panels, carried over from b3. Measured in
    the browser, this label renders its text at 75px minimum -- the box scales its
    own padding, so 60 is below the widget's floor and the last line was cut off.
    Both panels showed a half-line of text hanging past the canvas.
    Raised to 110, which measures 104 with room to spare. Anything from 90 up fits;
    110 absorbs a longer instruction.
    The real gap was in the generator, not the number. Both test panels were
    carried over from b3 verbatim rather than rebuilt, so they never went through
    the checks the other two panels get -- and the checks would not have caught it
    anywa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
    [03_bit-rxy.cpp]
2026-08-21 fix: answer GETCFGVER so a cached layout skips the transfer (S2-v2)
    Every connect paid for the whole layout, twice over: the app probes with
    GETCFGVER and this firmware swallowed it, so the app waited out its full
    3x900ms retry budget and only then fell back to GETCFG and downloaded all
    3.5 kB again -- a layout it very likely already had.
    The old comment justified staying silent by saying a reply would have to
    reproduce a hash the app computes independently, and that a mismatch would be
    silently permanent. That is not how the app works. saveCachedRemoteConfig()
    stores whatever string arrives in CFGVER verbatim and loadCachedRemoteConfig()
    compares it verbatim on the next connect, so the tok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
    [03_bit-rxy.cpp]
2026-08-21 fix: forward drive veered right — the trim was applied backwards (S2-v3)
    The right wheel is mirrored on the chassis, so its pulse range is inverted:
    map(rightSpeed, -100, 100, 180, 0) against the left's 0..180. The per-wheel
    trim is a raw pulse offset, so it lands in each servo's OWN frame -- and adding
    the same +5 to both pushed the two wheels in OPPOSITE physical directions.
    At full forward that gave:
    left 180 -> +90 from neutral (full speed)
    right 5 -> +85 from neutral (5 short of full speed)
    so the left wheel outran the right and the robot curved right, exactly as
    reported. At rest it was worse: 90+5 on the left creeps forward while 90+5 on
    the mirrored right creeps backw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
    [00_config.h, 03_bit-rxy.cpp, 04_tasks.cpp]
2026-08-21 feat: two-button Turn pad on the robot, and fix three clipped widgets (S2-v4)
    Adds dpad_turn, the app's new "leftright" D-pad model, to the Expert and Drive
    test panels. On a differential drive, left/right with no forward component
    spins the robot on the spot -- the one movement the 4-way pad makes awkward,
    since it needs a held direction and constant correction.
    It routes through handleDpad() with no new state. That function sets whichever
    cardinal bit arrives, so this pad's left/right merge into the same motion state
    as dpad_drive: holding forward on one and left on the other is an arc turn
    rather than the two pads fighting each other.
    Also fixes three widgets whose text was clipped, whi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
    [03_bit-rxy.cpp]
2026-08-21 feat: per-wheel trim sliders, set from the app and kept in NVS (S2-v5)
    Straightening the robot used to mean editing CONFIG_SERVO_SPEED_STOP_*_OFFSET
    and reflashing over USB, which is useless in a classroom: continuous-rotation
    servos vary unit to unit, so this is per-robot calibration, not a constant.
    trim_l and trim_r are now sliders in the Drive test and Expert panels, -20..20
    degrees of servo pulse, positive meaning that wheel drives more forward. They
    sit next to the drive controls on purpose -- you tune them WHILE driving
    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
2026-08-24 port: rewire for board 30_esp32_c3_move, and add the sonar head (MV-v1)
    Every pin moved. The servo-sonar board and this one share an MCU and nothing
    else, so the pin map was read out of 30_esp32_c3_move.kicad_pcb's netlist
    rather than trusted from the schematic, whose nets are all named `gpio_NN`.
    drive servos J5 / J12, GPIO 5 / 10, both level-shifted by the TXB0104
    HC-SR04 J10, GPIO 6 / 7, also level-shifted -- ECHO arrives at 3.3V
    instead of the 5V b3 feeds straight to a pin
    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
2026-08-24 hardware: ship the 30_esp32_c3_move board with the firmware that targets it
    v1 is the fabricated board and what 00_config.h is written against. v2 comes
    along too, with a README that is blunt about what it is: a byte-identical PCB
    carrying a to-do note, not a revision.
    The pin-map table is the one that was reconstructed from the PCB netlist while
    doing the port. Recording it next to the board matters because the schematic
    does not have it -- every net there is called gpio_NN.
    [30_esp32_c3_move.kicad_pcb, 30_esp32_c3_move.kicad_sch, bom.csv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]
2026-08-24 docs: rewrite the README for this board, and stop the stale site publishing
    README.md and README.html both describe 30_esp32_c3_move rather than the
    servo-sonar board they were inherited from: the fork chain b3 -> S2 -> here,
    the pin map, the head servo and the radar it feeds, and the three board facts
    that firmware cannot paper over.
    The Pages workflow loses its push trigger. 02_web/ documents b3's LEDs, strip,
    OLED and battery sense, and the staging step copies 02_hardware/v3/ which does
    not exist in this repo -- so the next push would have published a site
    confidently wrong about this robot. Manual dispatch still works, and the
    comment says what to fix before restoring the trigger.
2026-08-24 rebase the port on b3 itself, not on the reduced fork (MV-v1)
    The first pass built on esp32c3_super_mini_servo_sonar-rxy, on the reasoning
    that it had already dropped everything this board cannot feed. That was the
    wrong call: S2 is a SUBTRACTION of b3, so anything standing on it is
    unfaithful by construction -- five modules and four panels short before a line
    is written. 01_software/01_app is now b3's, wholesale.
    Faithfulness costs bodges, and the honest thing is to name them rather than
    quietly drop the features:
    buzzer GPIO 4, b3's own pin -- but soldered to SW2's pads, since the
    board has no buzzer footprint
    battery sense GPIO 4 as well, preserving b3's co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
    [layout_test_motors.json]
2026-08-24 fix: an absent OLED starved loop() and hung the app on "Checking layout version"
    The robot connected, then the app sat at 0% forever waiting on GETCFGVER.
    setup() logged a failed display.begin() and carried on regardless, and
    oled_update() runs every 100ms unconditionally. On b3 that is safe -- the
    screen is soldered to the board and always answers. Here the OLED is a bodge to
    the module's pads, because GPIO 8/9 reach no connector, so the usual case is no
    device and no pull-ups on the bus. Writing a frame to that is not a no-op: it
    is ~1KB of I2C transactions that each have to time out. At a 100ms cadence
    loop() barely runs, remotexy_handler() never gets to answer GETCFGVER, and the
    app wai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
    [01_src.ino, 13_oled.cpp]
2026-08-24 oled: re-probe while absent, and document the bodge wiring
    The screen is going to be fitted, so the boot probe is a safety net rather than
    the operating mode -- and a one-shot probe is the wrong safety net for four
    wires soldered to a module's pads. A wire that seats a moment late or works
    loose meant no screen until the next power cycle.
    oled_update() now looks again every five seconds while nothing is answering,
    and enables the screen the moment one does. One short transaction per five
    seconds is nothing; it was the ~1KB per frame at 100ms that had to stop.
    Wiring is written down because the two details that bite are not obvious: VCC
    must come from 3V3, since the module's own pull-ups fo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
    [13_oled.cpp]
2026-08-24 fix: answer GETCFGVER (MV-v2) - the rebase dropped it and the app hung
    Cherry-picked from S2's 0f9dff0. b3 recognises GETCFGVER and deliberately does
    not reply, using it only to fingerprint which app is talking. S2 fixed that;
    rebasing this port onto b3 for fidelity threw the fix away with it, and the app
    sat on "Checking layout version" forever.
    S2's commit message notes the app used to retry 3x900ms and then fall back to
    GETCFG on its own, which is why b3 survives without this. rxy_web v2.29 no
    longer falls back, so silence is now fatal rather than merely slow.
    Version bumped to MV-v2 rather than left at v1 on purpose: layoutRevision()
    folds B3_FIRMWARE_VERSION into the token, so this in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
    [03_bit-rxy.cpp]
2026-08-24 fix the halt in setup(), and compile out the hardware this board lacks
    THE HANG. ESP32Servo halts inside attach() when it runs out of PWM timers --
    it prints "All PWM timers allocated! Can't accomodate 50.000 Hz" and stops.
    b3 allocates ONE timer and attaches two servos, which exactly fits; the head
    servo made three and setup() never returned. Now allocates all four.
    That failure is invisible from the outside, which is what made it expensive:
    NimBLE starts on its own task before the servos are attached, so the robot
    still advertises and the app still connects -- it just never answers anything,
    because remotexy_handler() lives in loop() and loop() had never run. It
    presents as a protocol bug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
    [00_config.h, 01_src.ino, 03_bit-rxy.cpp]
2026-08-24 layout: strip the Expert panel to what this board actually has (MV-v3)
    Every group whose hardware is compiled out was a control that looked live and
    did nothing, which is the exact failure the layout checks exist to catch.
    removed DISPLAY entirely -- no OLED
    SOUND entirely -- no buzzer
    the six strip widgets from LIGHTS (toggle_np, np_effect, np_r/g/b,
    np_bright); the two board LEDs stay, they are real and their J7/J8
    headers even light the onboard yellows along with them
    moved TRIM is gone as a group; all eight of its widgets now sit inside
    DRIVE, which is where you use them -- you tune trim WHILE driving
    forw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
    [03_bit-rxy.cpp]
2026-08-24 chore: ignore PlatformIO's generated .ino.cpp
    It lands next to the source rather than under .pio, and it bakes in absolute
    temp paths from whichever machine built it. b3 does not track it either.
2026-08-24 drive direction, and a sweeping head that the radar can actually follow (MV-v4)
    FORWARD WAS BACKWARDS. Both wheels ran the wrong way, which is motor polarity
    rather than a left/right mix-up -- swapping the two pins would have given a
    robot that spins instead. CONFIG_SERVO_INVERT_DRIVE negates the command before
    the mix becomes pulses, so trim and the speed cap stay in the frame they were
    written for. It corrects the steering along with it: with the polarity wrong a
    spin-left command was coming out as spin-right, and fixing the sign fixes both.
    THE RADAR BEAM SAT AT 90 FOREVER. It plots at whatever the `head` widget last
    reported, and the firmware only ever sent that once, in the CFG echo. S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
    [00_config.h, 03_bit-rxy.cpp, 04_tasks.cpp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]
2026-08-24 docs: bring the README back in line with what the firmware now does
    Several sections had drifted into describing behaviour that was true for an
    hour and then changed:
    - the OLED was written up as "expected, not optional" with a live re-probe.
    It is compiled out; GPIO 8/9 are not wired on this board.
    - the radar was documented as living on the Distance test panel. It is on
    Expert, along with the head slider and the sweep toggle.
    - the flash figure was 92%, from before three subsystems were compiled out.
    Added what was missing: the PWM-timer halt and why it looks like a protocol
    bug, the drive inversion, how sweep is paced against the telemetry cycle, and
    what Expert lost.
    Bot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
2026-08-24 feat: head centring offset, adjustable from the app (MV-v5)
    A pan mount is glued or screwed on by hand, so commanding 90 degrees almost
    never points the sensor dead ahead. This is the difference, on a slider with
    H-1 / H+1 buttons for the last degree or two.
    The offset is applied where the servo is WRITTEN, never to the bearing that
    gets reported. s_head_angle stays "where the sensor is aimed" -- which is what
    the radar plots and what the app echoes -- and the correction lives only
    between that and the pulse. Reporting the raw pulse instead would smear every
    blip by the offset, which is the opposite of what centring is for.
    Clamped twice on purpose: the bearing to the mount's own MIN/MAX,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
    [00_config.h, 03_bit-rxy.cpp, 09_servos.cpp]
2026-08-24 fix: head trim now echoes back, and centring actually centres (MV-v6)
    Layout spliced from the app export (rev d2019221318), stripped of empty props
    bags, explicit nulls and fractional coordinates the firmware never reads --
    8844B down to 8096B of base64, which is transfer time over BLE on every cache
    miss.
    HEAD TRIM WAS NOT SYNCED. The handler saved to NVS but never staged an echo,
    so pressing H+1 moved the servo while the slider stayed where it was and the
    two disagreed about the offset. It now calls trimTouched() like the wheel
    trims do, and the echo walk covers five widgets instead of four.
    CENTRING WAS A NO-OP AT BOOT. centerHead() went through moveHead(), whose
    no-redundant-writes gua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
    [03_bit-rxy.cpp, 09_servos.cpp]
2026-08-24 feat: a Radar level of its own (MV-v7)
    The scope had to be hunted for inside Expert, next to everything else. It now
    has a panel: the radar, the head slider, Sweep, the head trim, and the distance
    gauge it is plotting -- so the panel explains itself, because you can see the
    number each blip came from.
    Two things a ninth level costs, neither obvious:
    - the enum entry is APPENDED, never inserted. The level index is stored in
    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
2026-08-24 fix: the Radar panel's hint was clipped mid-sentence (MV-v8)
    Wrote two sentences into a box sized for one, so the label ran off its own
    bottom edge and the last line was unreadable. A hint that gets cut off teaches
    nothing -- and this is precisely the failure S2's gen_layouts.py measured
    HINT_H to prevent, which I walked into by hand-authoring the blob.
    127 characters down to 49, and the box up from 700x110 to 760x150. The wording
    loses the explanation of what a blip is; that belongs in the wiki article,
    where there is room for it, not on a panel.
    [03_bit-rxy.cpp]
2026-08-24 fix: size the hint box to the text instead of cutting the text (MV-v9)
    MV-v8 fixed the clipping by shortening the sentence, which was the wrong end of
    the problem: the text was never too long, the box was too small. Screenshotted
    in Arrange mode the full wording renders perfectly well -- it just needed room.
    Full sentence restored, and the box now runs flush with the group's own left
    and right edges (980 wide) with headroom for five lines of the panel's large
    label font, so it cannot clip at any zoom the app renders at.
    Flashed and verified on the board.
    [03_bit-rxy.cpp]
